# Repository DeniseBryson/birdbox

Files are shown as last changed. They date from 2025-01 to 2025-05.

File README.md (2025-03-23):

# BirdsOS

BirdsOS is a Flask-based application for controlling and monitoring bird feeder hardware, with support for camera feeds and GPIO control. It includes development-friendly mock implementations for testing without physical hardware.

## Features

### Camera System
- Live video streaming with configurable resolution
- Recording capabilities with frame buffering
- Camera settings management
- Mock implementation for development with test pattern generation

### GPIO Control
- Hardware abstraction layer with Raspberry Pi detection
- Pin state monitoring and control
- Mock implementation for development and testing
- Interactive GPIO simulator interface

### Web Interface
- Main dashboard for system monitoring
- Camera simulator with live feed display
- GPIO simulator for hardware interaction
- RESTful API endpoints for system control

## Setup

1. Clone the repository:
```bash
git clone <repository-url>
cd birdbox
```

2. Install dependencies:
```bash
pip install -r requirements.txt
```

3. Run the application:
```bash
python app.py
```

The application will be available at:
- Main Dashboard: http://localhost:5000
- Camera Simulator: http://localhost:5000/camera
- GPIO Simulator: http://localhost:5000/gpio

## API Endpoints

### Camera Control
- `GET /video_feed` - Stream live video feed
- `POST /api/camera/record/start` - Start recording
- `POST /api/camera/record/stop` - Stop recording
- `POST /api/camera/settings` - Update camera settings
- `GET /api/camera/recordings` - List recorded videos

### GPIO Control
- `GET /api/gpio/status` - Get current pin states
- `POST /api/gpio/trigger` - Trigger input pin state change

### System Status
- `GET /status` - Get system operational status

## Development

The system includes mock implementations for both camera and GPIO functionality, allowing development and testing without physical hardware. When running on a Raspberry Pi, it automatically switches to using real hardware interfaces.

### Mock Implementations
- Camera mock generates test patterns with timestamps
- GPIO mock simulates pin state management
- Both provide realistic behavior for testing

## Current Status

### Implemented
- Core application structure
- Camera streaming and recording framework
- GPIO state management
- Web interface and simulators
- Hardware abstraction layer

### In Progress
- Motor control system
- Recording storage implementation
- Full status monitoring
- Enhanced simulator features

## Contributing

Contributions are welcome! Please feel free to submit pull requests or open issues for bugs and feature requests.

## License

[License information to be added]

# BirdBox - Training Wild Birds to Clean the Environment

The BirdBox project is an innovative approach to environmental cleanup that trains wild birds to collect litter in exchange for food. This project combines environmental conservation with animal intelligence, creating a sustainable way to help clean our environment while engaging with local wildlife.

## Overview

The BirdBox is a device designed to train wild crows to pick up litter and deposit it into a designated container in exchange for food rewards. This project leverages the natural intelligence and adaptability of corvids (crows and ravens) to create a mutually beneficial relationship between humans and birds while addressing environmental pollution.

## How It Works

The system works on a simple principle: when a bird deposits litter into the collection area, it triggers sensors that activate a food dispenser, rewarding the bird with a treat. Over time, birds learn to associate cleaning up litter with receiving food rewards, creating a sustainable cycle of environmental cleanup.

## Project Goals

- Create a sustainable solution for environmental cleanup
- Engage wild birds in a meaningful way that benefits both wildlife and humans
- Raise awareness about environmental issues and animal intelligence
- Demonstrate how technology can be used to create innovative solutions for environmental challenges

## Community Impact

This project not only helps clean the environment but also:
- Creates awareness about environmental pollution
- Demonstrates the intelligence of wild birds
- Provides a unique way for communities to engage with local wildlife
- Offers an educational opportunity to learn about animal behavior and environmental conservation

## Contributing

This is an open-source project, and we welcome contributions from the community. Whether you're interested in hardware improvements, software development, or documentation, your input is valuable to the project's success.

## License

This project is licensed under the Creative Commons - Attribution - Non-Commercial license.

Spezifikation:
Motordurchmesser: 6 mm
Motorlänge: 12 mm
Kabellänge: 65 mm
Gewicht: 2 g
Spannungsbereich: 3,0 V -3,7 V
Testdaten:
Spannung: 3,0 V Strom: 160 mA
Spannung: 3,7 V Strom: 220 mA

# Camera Case
The Camera Case was used from https://www.thingiverse.com/thing:2317664 and modified, to make it attachable to the backboard.

## Installation

### Automated Setup (Raspberry Pi)

The project includes an automated setup script designed for Raspberry Pi (optimized for Pi 3B). The script handles all necessary installation steps, including:
- System dependencies
- Python environment
- Hardware configuration
- Service setup
- Storage management

#### Prerequisites
- Raspberry Pi (3B recommended) with Raspberry Pi OS
- Internet connection
- GitHub account (for SSH key setup)
- At least 32GB SD card (Class 10 recommended)

#### Installation Steps

1. **Download the Setup Script**
   ```bash
   curl -O https://raw.githubusercontent.com/DeniseBryson/birdbox/AIgen2/setup.sh
   chmod +x setup.sh
   ```
   or upload via scp:
   ```bash
   scp "setup.sh" birds@<ip-address>:/home/birds/
   ```

2. **Run the Setup Script**
   ```bash
   ./setup.sh
   ```

   The script will:
   - Check if running on a Raspberry Pi
   - Set up SSH keys if needed
   - Install all dependencies
   - Configure camera and GPIO interfaces
   - Set up the Python environment
   - Create necessary directories
   - Configure storage based on available space
   - Run tests to verify the installation
   - Set up the system service

3. **Post-Installation**
   - The service will start automatically
   - Access the web interface at `http://localhost:5000`
   - Check the service status with `sudo systemctl status birdbox`

#### Configuration
The script creates a `.env` file with default settings optimized for Raspberry Pi 3B:
- Camera: 640x480 @ 20fps
- Storage: 75% of available SD card space
- GPIO: BCM mode
- Logging: Daily rotation, 14 days retention

#### Troubleshooting
- If tests fail during installation, you can choose to:
  1. Exit and fix the issues
  2. Continue with the installation (not recommended)
- Check logs in `~/birdbox/storage/logs/`
- Monitor system temperature with `vcgencmd measure_temp`
- Monitor resources with `htop`

#### Manual Installation
For non-Raspberry Pi systems or manual installation, please refer to the [Manual Installation Guide](docs/manual_installation.md).

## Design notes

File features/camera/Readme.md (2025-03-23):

# Camera Feature Documentation

## Overview
The camera feature provides functionality for camera control, live streaming, and video recording in BirdsOS.

## API Endpoints

### Status and Control
- `GET /api/v1/camera/status`
  - Returns camera status and available devices
  - Response: 
    ```json
    {
      "active_camera": 0,
      "status": "active",
      "camera_info": {
        "id": 0,
        "resolution": [1280, 720],
        "is_running": true,
        "status": "active"
      },
      "available_cameras": [
        {"id": 0, "status": "available"}
      ]
    }
    ```

- `POST /api/v1/camera/initialize/<camera_id>`
  - Initialize and start a specific camera
  - Response (success):
    ```json
    {
      "status": "success",
      "message": "Camera {id} initialized"
    }
    ```
  - Response (error):
    ```json
    {
      "status": "error",
      "message": "Failed to initialize camera {id}"
    }
    ```

- `POST /api/v1/camera/stop`
  - Stop the currently active camera
  - Response:
    ```json
    {
      "status": "success",
      "message": "Camera stopped"
    }
    ```

## Technical Details

### Camera Class
The `Camera` class provides low-level camera operations:
- Device initialization
- Frame capture
- Status monitoring
- Device enumeration

### Camera Manager
The `CameraManager` handles:
- Camera lifecycle management
- High-level operations
- Status tracking
- Resource cleanup

## Dependencies
- OpenCV (`opencv-python==4.9.0.80`)
- NumPy (`numpy<2.0`)
- Flask for API endpoints

## Testing
All components are tested with:
- Unit tests for Camera class
- Unit tests for CameraManager
- Integration tests for routes
- Mocked hardware for reliable testing

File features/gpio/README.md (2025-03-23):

# GPIO Control Feature

This feature provides comprehensive GPIO (General Purpose Input/Output) control functionality for the BirdsOS project, with support for both real Raspberry Pi hardware and development environments.

## Features

- Hardware abstraction layer for GPIO control
- Real-time pin state monitoring
- Input/Output mode configuration
- Pin state toggling for output pins
- Mock implementation for development
- WebSocket-based real-time updates
- Comprehensive test coverage

## Quick Start

1. Import and register the GPIO blueprints in your Flask app:

```python
from features.gpio import gpio_bp, sock

app.register_blueprint(gpio_bp)
sock.init_app(app)
```

2. Access the GPIO control interface at `/gpio`

## API Endpoints

### Get Available Pins
```http
GET /api/gpio/pins

Response:
{
    "status": "success",
    "pins": [2, 3, 4, ...],
    "states": {
        "2": {
            "pin": 2,
            "mode": "IN",
            "state": 0,
            "name": "GPIO2"
        },
        ...
    }
}
```

### Configure Pin Mode
```http
POST /api/gpio/configure
Content-Type: application/json

{
    "pin": 2,
    "mode": "OUT"  // "IN" or "OUT"
}

Response:
{
    "status": "success",
    "state": {
        "pin": 2,
        "mode": "OUT",
        "state": 0,
        "name": "GPIO2"
    }
}
```

### Set Pin State
```http
POST /api/gpio/state
Content-Type: application/json

{
    "pin": 2,
    "state": 1  // 0 or 1
}

Response:
{
    "status": "success",
    "state": {
        "pin": 2,
        "mode": "OUT",
        "state": 1,
        "name": "GPIO2"
    }
}
```

### Cleanup GPIO Resources
```http
POST /api/gpio/cleanup

Response:
{
    "status": "success",
    "message": "GPIO cleanup completed"
}
```

## WebSocket Updates

Connect to `/ws/gpio-updates` for real-time GPIO state updates:

```javascript
const ws = new WebSocket('ws://' + location.host + '/ws/gpio-updates');
ws.onmessage = (event) => {
    const data = JSON.parse(event.data);
    if (data.type === 'gpio_update') {
        // Handle pin states update
        console.log(data.data.states);
    }
};
```

## Development

### Running Tests

```bash
pytest features/gpio/tests/
```

### Mock Implementation

The feature automatically detects if it's running on a Raspberry Pi. If not, it uses a mock implementation that simulates GPIO behavior, perfect for development and testing.

### Adding New GPIO Features

1. Implement the feature in `manager.py`
2. Add corresponding API endpoints in `routes.py`
3. Add tests in `tests/`
4. Update the UI in `templates/gpio_control.html`

## Example Usage

### Python Code
```python
from features.gpio import GPIOManager

# Initialize GPIO manager
gpio = GPIOManager()

# Configure pin as output
gpio.configure_pin(18, 'OUT')

# Set pin high
gpio.set_pin_state(18, 1)

# Get pin state
state = gpio.get_pin_state(18)
print(f"Pin 18 is {'HIGH' if state['state'] else 'LOW'}")

# Cleanup when done
gpio.cleanup()
```

### JavaScript Code
```javascript
// Initialize GPIO controller
const controller = new GPIOController();

// Configure pin as output
await controller.configurePin(18, 'OUT');

// Toggle pin state
await controller.togglePinState(18, 1);
```

## Security Considerations

1. Pin access is restricted to valid GPIO pins only
2. Input validation for all API endpoints
3. Error handling for hardware failures
4. Automatic cleanup on application shutdown

## Contributing

1. Fork the repository
2. Create a feature branch
3. Add your changes
4. Add tests for your changes
5. Submit a pull request

## License

This feature is part of the BirdsOS project and is licensed under the same terms.

## Test Coverage TODO

### UI Tests
- [ ] Test pin selection dropdown population
- [ ] Test mode switching (Input/Output)
- [ ] Test pin state indicators
- [ ] Test pin overview table updates
- [ ] Test toggle button functionality
- [ ] Test real-time updates
- [ ] Test mobile responsiveness
- [ ] Test browser compatibility (Chrome, Firefox, Safari)
- [ ] Test concurrent user interactions
- [ ] Test UI state consistency with backend
- [ ] Test UI behavior during network latency

### Error Handling Tests
- [ ] Test concurrent access to same GPIO pin
- [ ] Test hardware access failures
- [ ] Test application shutdown cleanup
- [ ] Test WebSocket connection drops
- [ ] Test invalid API responses
- [ ] Test error message display in UI
- [ ] Test recovery after errors
- [ ] Test rate limiting behavior
- [ ] Test timeout handling
- [ ] Test invalid state transitions

### Performance Tests
- [ ] Test response time under load
- [ ] Test WebSocket update frequency
- [ ] Test memory usage with multiple clients
- [ ] Test WebSocket client cleanup
- [ ] Test UI performance with many pins
- [ ] Test rapid state changes
- [ ] Test concurrent API requests
- [ ] Test data throughput limits
- [ ] Test browser resource usage
- [ ] Test backend resource usage

### Integration Tests
- [ ] Test GPIO and motor control interaction
- [ ] Test state persistence across restarts
- [ ] Test mock/real hardware switching
- [ ] Test rapid mode switching
- [ ] Test with other system components
- [ ] Test startup sequence
- [ ] Test shutdown sequence
- [ ] Test system state recovery
- [ ] Test configuration changes
- [ ] Test logging integration

### Security Tests
- [ ] Test access control for endpoints
- [ ] Test input sanitization
- [ ] Test WebSocket authentication
- [ ] Test API rate limiting
- [ ] Test permission levels
- [ ] Test data validation
- [ ] Test error exposure
- [ ] Test secure connections
- [ ] Test session handling
- [ ] Test audit logging

### Edge Cases
- [ ] Test boundary values for pin numbers
- [ ] Test maximum WebSocket connections
- [ ] Test invalid JSON payloads
- [ ] Test unicode input
- [ ] Test large data payloads
- [ ] Test rapid connection/disconnection
- [ ] Test browser tab switching
- [ ] Test system resource limits
- [ ] Test error condition combinations
- [ ] Test recovery scenarios

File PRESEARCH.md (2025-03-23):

# BirdBox Web Interface - Pre-Research Document

## 1. Core Features Overview

### 1.1 Storage & Statistics
- Local storage on Raspberry Pi
- Default 10GB storage limit
- Warning at 85% capacity
- Hourly statistics
- CSV export capability

```python
class StorageManager:
    DEFAULT_STORAGE_LIMIT = 10 * 1024 * 1024 * 1024  # 10GB
    WARNING_THRESHOLD = 0.85

    def check_storage(self):
        total, used, free = shutil.disk_usage("/")
        return {
            "total": total,
            "used": used,
            "free": free,
            "warning": used / total > self.WARNING_THRESHOLD
        }
```

### 1.2 Configuration Profiles
- Persistent storage
- Multiple profiles support
- Configurable parameters:
  - Motor frequencies
  - Sensor sensitivity
  - Feeding delays

```python
class ConfigProfile:
    def __init__(self):
        self.config = {
            "name": "Default",
            "motor_frequency": {
                "min": 10,
                "max": 100,
                "default": 50
            },
            "sensor_sensitivity": 0.75,
            "feeding_delay": 5  # seconds
        }
```

### 1.3 Maintenance Functions
- Food level estimation based on motor runtime
- Statistical optimization
- Manual reset with backdating capability
- Basic maintenance logging

```python
class FoodLevelEstimator:
    def __init__(self):
        self.motor_runtime = 0
        self.last_refill = datetime.now()
        self.food_per_second = 0.5  # g/s
```

### 1.4 Notifications (Telegram)
- Internet connectivity check
- Configuration via UI
- Visual status indication
- Priority levels

```python
class NotificationManager:
    def __init__(self):
        self.telegram_token = None
        self.chat_id = None

    def check_connection(self):
        try:
            return requests.get('https://api.telegram.org',
                              timeout=5).status_code == 200
        except:
            return False
```

### 1.5 Camera Integration
- Buffer: 10s before trigger
- Post-event: 20s after motor stop
- Configurable resolution
- Storage management
- Email warnings before deletion

```python
class CameraManager:
    def __init__(self):
        self.buffer_time = 10
        self.post_time = 20
        self.resolution = (1280, 720)
        self.format = 'h264'
```

### 1.6 Research Data
- CSV export functionality
- Configurable data points
- Offline availability
- Storage monitoring

```python
class ResearchData:
    data_points = {
        "timestamp": [],
        "sensor_triggers": [],
        "motor_runtime": [],
        "estimated_food": [],
        "temperature": [],
        "video_references": []
    }
```

## 2. UI Design

### 2.1 Dashboard Layout
```html
<div class="dashboard">
    <div class="stats-cards">
        <!-- Statistics Cards -->
    </div>
    <div class="charts">
        <!-- Interactive Charts -->
    </div>
    <div class="config-panel">
        <!-- Configuration Interface -->
    </div>
</div>
```

### 2.2 Responsive Design
- Mobile-first approach
- Flexible grid system
- Touch-friendly controls

## 3. Future Extensions

### 3.1 Bird Species Recognition
- TensorFlow Lite implementation
- Pre-trained MobileNet model
- Transfer learning capability
- Local inference
- Movement pre-filtering

### 3.2 Advanced Analytics
- Pattern recognition
- Behavior analysis
- Weather correlation
- Feeding optimization

## 4. Technical Requirements

### 4.1 Hardware
- Raspberry Pi
- Camera module
- GPIO sensors
- Motors
- SD card (min. 16GB recommended)

### 4.2 Software
- Python 3.7+
- Flask
- OpenCV
- TensorFlow Lite (optional)
- SQLite/JSON storage

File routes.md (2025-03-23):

# BirdsOS Route Structure

## Main Routes

### Dashboard (/)
- Main system overview
- Quick status cards
- Latest activity feed
- System health indicators

### Camera (/camera)
- Live video feed
- Recording controls
- Camera settings
- Recent recordings list

### Hardware Control (/hardware)
- GPIO status and control
- Motor controls
- Sensor readings
- Hardware diagnostics

### Configuration (/config)
- System settings
- Profile management
- Hardware configuration
- Notification settings

### Maintenance (/maintenance)
- Food level monitoring
- System maintenance
- Storage management
- Backup controls

### Analytics (/analytics)
- Activity statistics
- Bird visit data
- Feeding patterns
- Weather correlation

## API Routes

### System API (/api/v1/system)
- GET  /status
- POST /restart
- GET  /storage
- GET  /health

### Camera API (/api/v1/camera)
- GET  /stream
- POST /record/start
- POST /record/stop
- GET  /recordings
- POST /settings

### Hardware API (/api/v1/hardware)
- GET  /gpio/status
- POST /gpio/trigger
- GET  /motors/status
- POST /motors/control
- GET  /sensors/readings

### Configuration API (/api/v1/config)
- GET  /profiles
- POST /profiles
- PUT  /profiles/{id}
- GET  /settings
- PUT  /settings

### Maintenance API (/api/v1/maintenance)
- GET  /food-level
- POST /food-refill
- GET  /storage/status
- POST /backup

### Analytics API (/api/v1/analytics)
- GET  /statistics
- GET  /visits
- GET  /patterns
- GET  /weather-data

## WebSocket Routes (/ws)
- /camera-feed
- /sensor-updates
- /system-status
- /notifications

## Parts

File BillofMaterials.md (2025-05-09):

|Description | Name | Amount  | EAN  | Price  | Comment |
|---|---|---|---|---|---|
| Water proof case for electronics 34cmx23cmx12,5cm | Wetterschutzbox  |  1 | 4007123673896  | 25 € (Germany, 2024)  ||
| M3 Screw  | ISO 1207 - M3 x 10 <br>ISO 1207 - M3 x 16<br>ISO 1207 - M3 x 30|8<br>8<br>8  | | 3 x 2,19 € (Germany, 2024)  ||
| hose for the nuts to fall 19mm inside/appr. 22mm outside | Ablaufschlauch | 1m  | 4007111115797  | 7,20 € (Germany, 2024)  |Could be bigger|
|M3 Nuts| ISO 4032 - M3|30|-|69,50 €/kg (Germany, 2024) | |
|rubber seal|Ventilteller-Dichtung|4|4053452014435||to cushion the feeder|
|IR EMITTER 940NM 100MA RADIAL| TSAL 6400 |4|-|0,25 € (Germany, 2024)|opitcal gate emitter|
|SENSOR PHOTODIODE 900NM| SFH 203 FA |2|-|0,90 € (Germany, 2024)|opitcal gate reciever|
|Comperator|LM324L|1|-|1 € (Germany, 2025)|Creates a clear on and off signal of the optical gate reciever outputs|
|Resistors|1M Ohm <br> 220 Ohm <br> 22k Ohm |4 <br> 2 <br> 1|-|0,10 €|Can just be bought in sets|
|Potentiometer|10kOhm Potentiometer|1|-|1€|To set the comparative voltage for the Comperator|
|MOSFET Motor Control Module|D4184 Mosfet Module|1|-|2,90 € (Germany, 2025)||
|DC Motor |DC 3V,3800rpm, D=17x23mm|1b\s-|2,50€ (Germany, 2025)||
|Wires||||||
|LAN Cable|-|1|-|-|An old cable with 8 wires to connect the optical food gate with the box, choose most flexible|
|Raspberry Pi|Raspberry Pi 3 Model B|1|-|appr. 30 €|Any Pi will work as long it has enough pins|

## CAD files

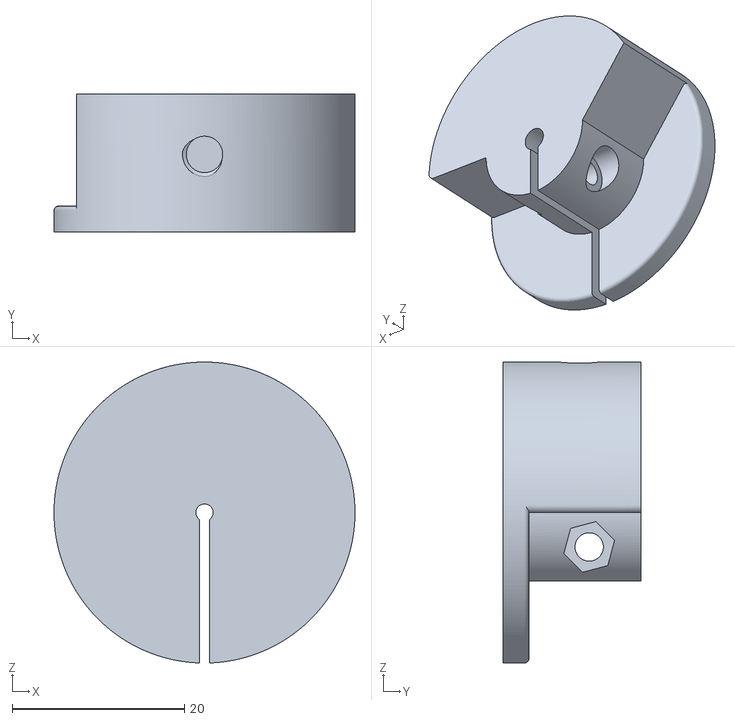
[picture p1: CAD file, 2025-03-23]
DesignFiles/birdbox/ModifiedFiles/BirdBox_vibr_flywheel_3mm.stl
35.0 x 16.0 x 35.0

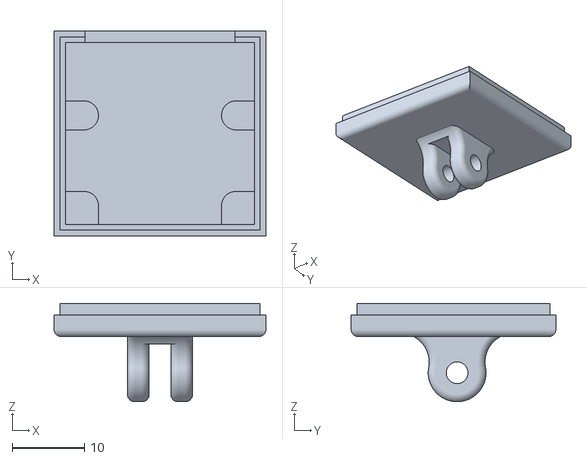
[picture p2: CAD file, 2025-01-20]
DesignFiles/CameraMount/Bottom_CameraCase.stl
29.3 x 28.3 x 13.6

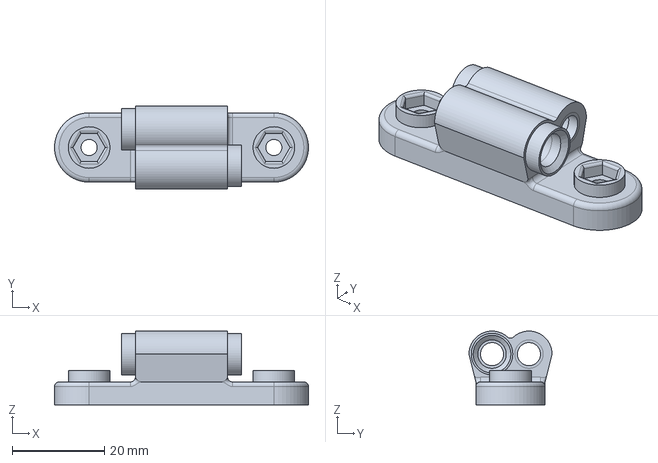
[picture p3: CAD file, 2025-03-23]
DesignFiles/VibroTroughFeeder/ModifiedFiles/VibroMotorMount_processdirection.FCStd
55.0 x 18.0 x 16.0 mm

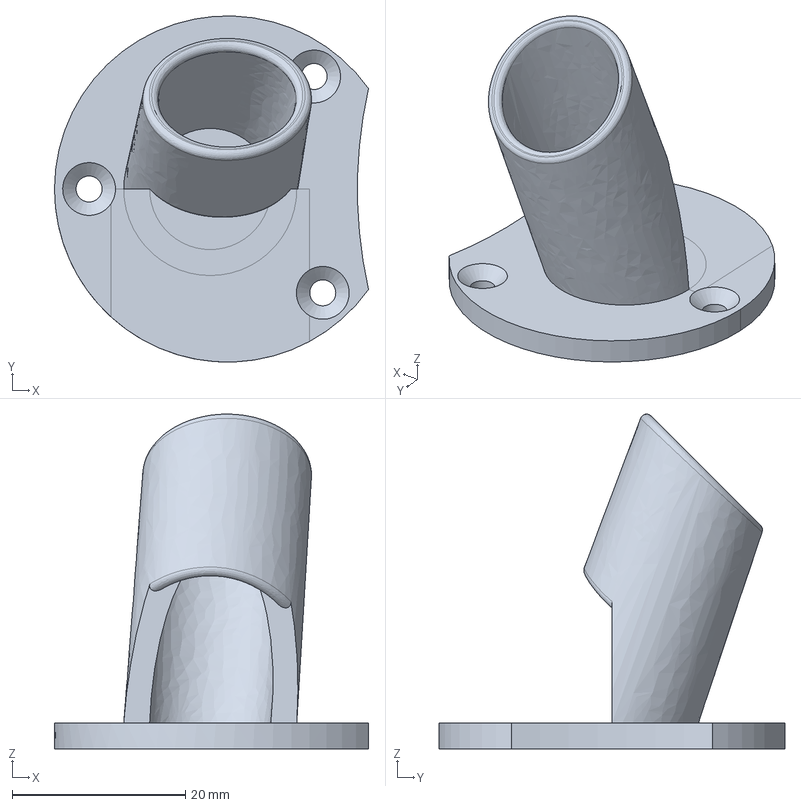
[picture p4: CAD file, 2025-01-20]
DesignFiles/birdbox/ModifiedFiles/NutReciever_Male.FCStd
36.3 x 40.0 x 38.7 mm

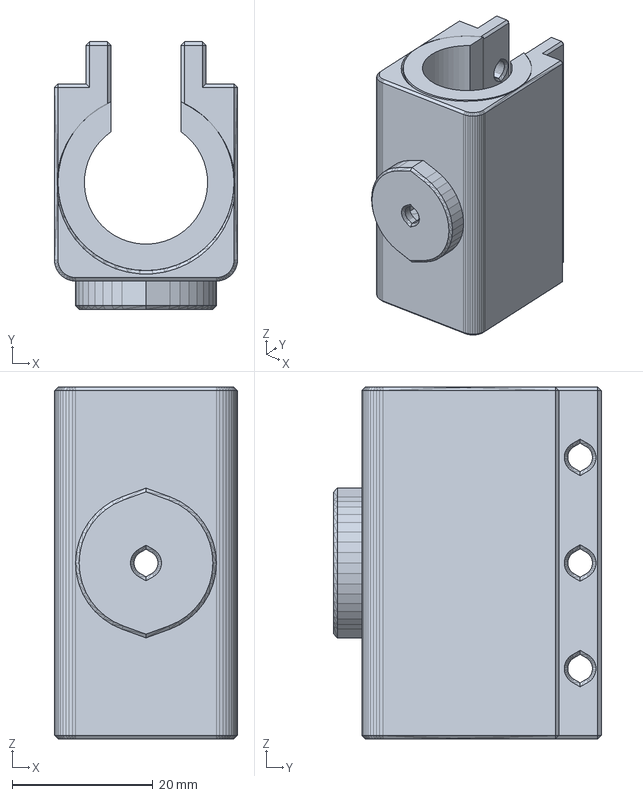
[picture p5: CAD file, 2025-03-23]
DesignFiles/VibroTroughFeeder/ModifiedFiles/Vibrating_Motor_Mount-Linear_Vibrator_Measured.FCStd
26.0 x 38.0 x 50.0 mm

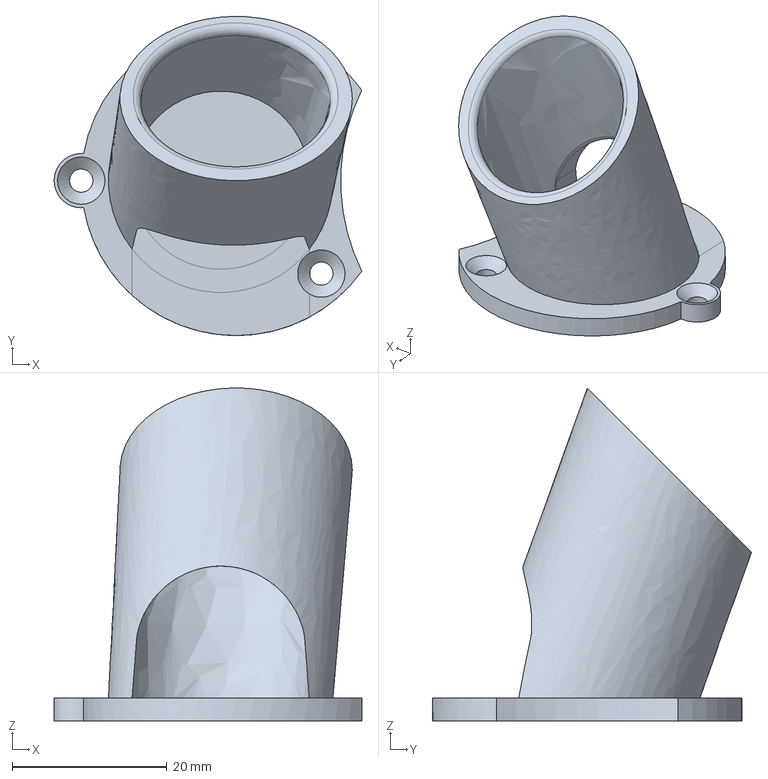
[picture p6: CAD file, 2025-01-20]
DesignFiles/birdbox/ModifiedFiles/NutReciever.FCStd
39.7 x 41.2 x 43.0 mm

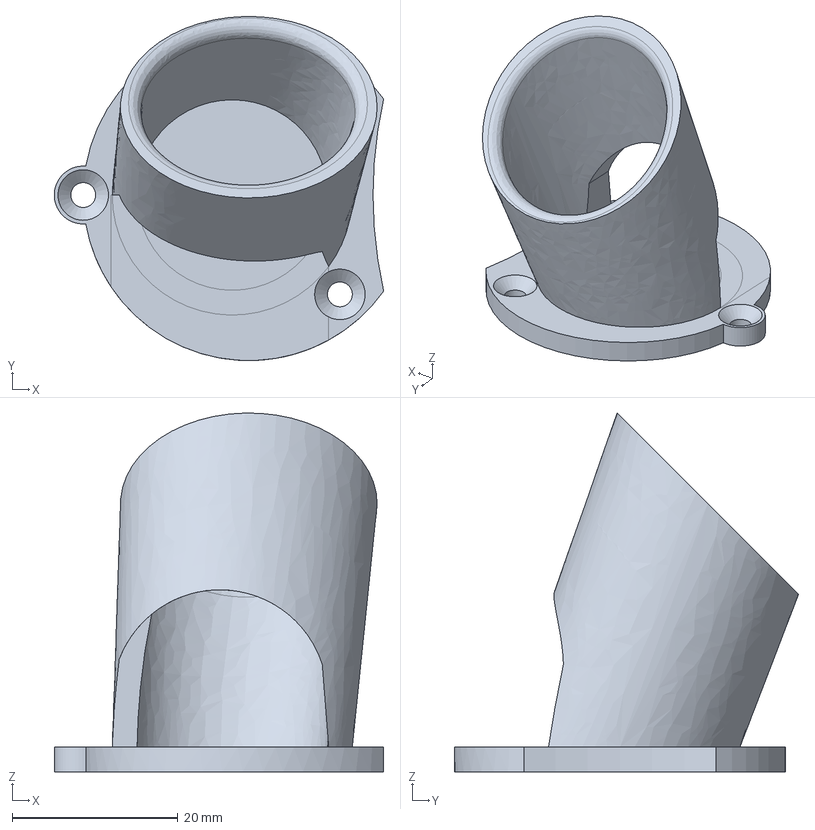
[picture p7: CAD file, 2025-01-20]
DesignFiles/birdbox/ModifiedFiles/NutReciever_Female.FCStd
39.8 x 41.5 x 43.3 mm

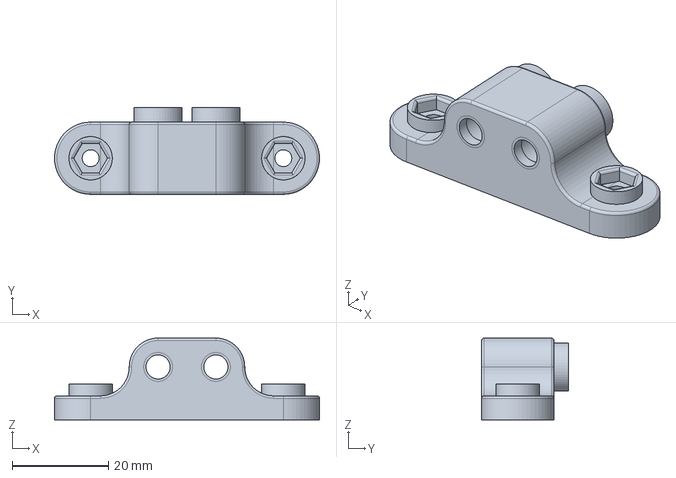
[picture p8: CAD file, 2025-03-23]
DesignFiles/VibroTroughFeeder/ModifiedFiles/VibroMotorMount.FCStd
55.0 x 18.0 x 17.0 mm

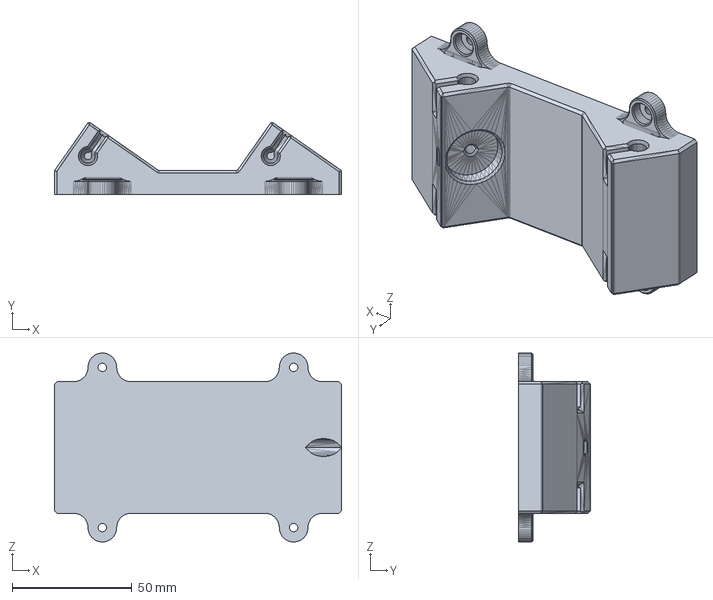
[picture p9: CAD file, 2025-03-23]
DesignFiles/VibroTroughFeeder/ModifiedFiles/BottomVibroMountPlate.FCStd
120.0 x 30.1 x 79.0 mm

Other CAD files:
DesignFiles/CameraMount/Bottom_MountHorizontal.FCStd
DesignFiles/VibroTroughFeeder/ModifiedFiles/VibroMotorMount_17mm.stl
DesignFiles/VibroTroughFeeder/ModifiedFiles/VibroMotorMount_processdirection.stl
DesignFiles/birdbox/ModifiedFiles/NutReciever_Female.stl
DesignFiles/birdbox/ModifiedFiles/NutReciever_Male.stl

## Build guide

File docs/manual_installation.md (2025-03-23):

# Manual Installation Guide

This guide provides step-by-step instructions for manually installing BirdsOS on any system. While the project is optimized for Raspberry Pi, you can run it on other systems for development or testing purposes.

## System Requirements

### Minimum Requirements
- Python 3.7 or higher
- 1GB RAM
- 1GB free disk space
- Webcam (for camera features)
- GPIO capability (for hardware control features)

### Development Mode Requirements
- Python 3.7 or higher
- 2GB RAM
- 5GB free disk space
- Any webcam (optional, mock camera available)
- No GPIO required (mock GPIO available)

## Installation Steps

### 1. Prepare the Environment

```bash
# Create and enter project directory
mkdir birdbox
cd birdbox

# Create Python virtual environment
python3 -m venv venv
source venv/bin/activate  # On Windows: .\venv\Scripts\activate
```

### 2. Clone the Repository

```bash
git clone https://github.com/DeniseBryson/birdbox.git .
```

### 3. Install Dependencies

```bash
# Upgrade pip
pip install --upgrade pip

# Install system packages (Ubuntu/Debian)
sudo apt-get update
sudo apt-get install -y \
    python3-opencv \
    libatlas-base-dev \
    libgstreamer1.0-0 \
    gstreamer1.0-tools \
    gstreamer1.0-plugins-good

# Install Python requirements
pip install -r requirements.txt
```

For other operating systems, install equivalent packages using your system's package manager.

### 4. Create Configuration

Create a `.env` file in the project root:

```bash
# Create and edit .env file
cat > .env << EOL
# BirdsOS Environment Configuration
FLASK_APP=app.py
FLASK_ENV=development  # Change to 'production' for production setup
SECRET_KEY=$(python3 -c 'import secrets; print(secrets.token_hex(16))')
MAX_CONTENT_LENGTH=16777216

# Storage Configuration
STORAGE_PATH=./storage
MAX_STORAGE_GB=5
WARNING_THRESHOLD=0.85

# Camera Configuration
CAMERA_RESOLUTION_WIDTH=640
CAMERA_RESOLUTION_HEIGHT=480
CAMERA_FRAMERATE=30
CAMERA_FORMAT=h264
CAMERA_BUFFER_TIME=5
CAMERA_POST_TIME=10

# GPIO Configuration
ENABLE_HARDWARE=false  # Set to true only if GPIO hardware is available
GPIO_MODE=BCM

# WebSocket Configuration
WS_ENABLED=true

# Testing Configuration
TESTING=false
EOL
```

### 5. Create Required Directories

```bash
# Create storage structure
mkdir -p storage/{recordings,logs}
```

### 6. Run Tests

```bash
# Run the test suite
python -m pytest
```

### 7. Development Server

```bash
# Start the development server
python app.py
```

The application will be available at `http://localhost:5000`

## Production Deployment

For production deployment, additional steps are recommended:

### Using Systemd (Linux)

1. Create a service file:
```bash
sudo nano /etc/systemd/system/birdbox.service
```

2. Add the following content (adjust paths as needed):
```ini
[Unit]
Description=BirdsOS Web Interface
After=network.target

[Service]
User=<your-username>
WorkingDirectory=/path/to/birdbox
Environment="PATH=/path/to/birdbox/venv/bin"
Environment="PYTHONUNBUFFERED=1"
Environment="FLASK_APP=app.py"
Environment="FLASK_ENV=production"
ExecStart=/path/to/birdbox/venv/bin/python app.py
Restart=always
RestartSec=10

[Install]
WantedBy=multi-user.target
```

3. Enable and start the service:
```bash
sudo systemctl enable birdbox
sudo systemctl start birdbox
```

### Using Docker

A Dockerfile is provided for containerized deployment. Build and run with:

```bash
docker build -t birdbox .
docker run -p 5000:5000 birdbox
```

## Troubleshooting

### Common Issues

1. **Camera Not Working**
   - Check if OpenCV is installed correctly
   - Verify camera permissions
   - Try running with mock camera: Set `ENABLE_HARDWARE=false` in `.env`

2. **GPIO Errors**
   - Verify GPIO library installation
   - Check hardware permissions
   - Use mock GPIO for testing: Set `ENABLE_HARDWARE=false` in `.env`

3. **Permission Issues**
   - Ensure correct file permissions on storage directories
   - Check user permissions for camera/GPIO access

### Logs

- Application logs: `storage/logs/birdbox.log`
- Error logs: `storage/logs/birdbox_error.log`

## Development Mode

For development, set these environment variables:
```bash
export FLASK_ENV=development
export FLASK_DEBUG=1
```

This enables:
- Debug mode
- Auto-reload on code changes
- Detailed error pages
- Mock hardware support

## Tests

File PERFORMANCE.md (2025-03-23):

# BirdsOS Deployment Guide - Raspberry Pi 3B

## Hardware Limitations & Considerations

### Memory (1GB RAM)
- Monitor memory usage with multiple WebSocket connections
- Implement cleanup routines for unused resources
- Limit video buffer sizes
- Consider reducing default camera resolution

### Storage
- Default 10GB storage limit should be adjusted:

```python
DEFAULT_STORAGE_LIMIT = 5 1024 1024 1024 # 5GB instead of 10GB
WARNING_THRESHOLD = 0.80 # Earlier warning
```

- Use high-quality Class 10 SD card (minimum 16GB recommended)

### GPIO
- 40 GPIO pins available
- 3.3V voltage levels only
- Use hardware PWM pins for motor control
- Consider cooling solutions for multiple GPIO outputs

## Performance Optimizations

### Camera Settings

```python
    class CameraManager:
    def init(self):
    self.buffer_time = 5 # Reduced from 10s
    self.post_time = 10 # Reduced from 20s
    self.resolution = (640, 480) # Lower resolution
    self.format = 'h264' # Hardware encoding
```

### Background Tasks

```python
from threading import Timer
class OptimizedStorageManager:
def schedule_cleanup(self):
Timer(3600, self.cleanup_old_files).start() # Hourly cleanup
```

### Database Optimization

```python
import sqlite3
class ResearchData:
def init(self):
self.db_path = 'research.db'
self.init_db()
def init_db(self):
with sqlite3.connect(self.db_path) as conn:
conn.execute('''CREATE TABLE IF NOT EXISTS measurements
(timestamp INTEGER PRIMARY KEY,
sensor_triggers INTEGER,
motor_runtime REAL)''')
```

## Software Setup

### Operating System
- Use Raspberry Pi OS Lite (minimal) for better performance

### Required Packages

```bash
sudo apt-get update
sudo apt-get install -y python3-pip python3-opencv
sudo apt-get install -y libatlas-base-dev # For numpy
sudo apt-get install -y python3-rpi.gpio
```

### Python Dependencies
Create `requirements.txt`:
```text
Flask
RPi.GPIO
opencv-python-headless # Lighter than full opencv
numpy
requests # For Telegram notifications
```

### Network Configuration
```bash
sudo raspi-config
Enable:
- Camera
- SSH (for remote management)
- I2C (if using sensors)
```

## System Service Setup

Create service file at `/etc/systemd/system/birdsos.service`:
```ini
[Unit]
Description=BirdsOS Service
After=network.target
[Service]
ExecStart=/usr/bin/python3 /path/to/app.py
WorkingDirectory=/path/to/project
User=pi
Restart=always
Environment=PYTHONUNBUFFERED=1
[Install]
WantedBy=multi-user.target
```
Enable and start service:

```bash
sudo systemctl enable birdsos
sudo systemctl start birdsos
```

## Monitoring

### System Resource Monitoring
```python
import psutil
def check_system_resources():
return {
"cpu_percent": psutil.cpu_percent(),
"memory_percent": psutil.virtual_memory().percent,
"disk_percent": psutil.disk_usage('/').percent,
"temperature": get_cpu_temperature()
}
def get_cpu_temperature():
try:
with open('/sys/class/thermal/thermal_zone0/temp', 'r') as f:
return float(f.read().strip()) / 1000
except:
return None
```

## Pre-deployment Checklist

1. Hardware
   - [ ] SD card installed and formatted
   - [ ] Camera module connected
   - [ ] GPIO connections verified
   - [ ] Cooling solution in place if needed

2. Software
   - [ ] OS installed and updated
   - [ ] Required packages installed
   - [ ] Python dependencies installed
   - [ ] Service file configured

3. Configuration
   - [ ] Storage limits adjusted
   - [ ] Camera settings optimized
   - [ ] Network interfaces enabled
   - [ ] Database initialized

4. Testing
   - [ ] Memory usage monitored
   - [ ] Camera functionality verified
   - [ ] GPIO operations tested
   - [ ] Service auto-restart confirmed

## Maintenance Recommendations

1. Regular Monitoring
   - Check system logs daily
   - Monitor storage usage
   - Review temperature readings
   - Verify database size

2. Periodic Tasks
   - Clean old log files
   - Backup database
   - Update system packages
   - Check SD card health

3. Performance Checks
   - Monitor memory leaks
   - Check CPU usage patterns
   - Verify camera buffer handling
   - Test GPIO responsiveness

## Troubleshooting

### Common Issues
1. High Memory Usage
   - Check WebSocket connections
   - Verify video buffer cleanup
   - Monitor Python process memory

2. Storage Problems
   - Review cleanup routines
   - Check log rotation
   - Verify database size

3. GPIO Issues
   - Verify voltage levels
   - Check pin assignments
   - Test for interference

### Debug Commands

```bash
Check service status
sudo systemctl status birdsos
View logs
journalctl -u birdsos
Monitor system resources
top
htop (if installed)
Check temperature
vcgencmd measure_temp
View GPIO status
gpio readall
```

## Notes
- Always test thoroughly with actual hardware
- Monitor performance during initial deployment
- Keep backup of SD card after successful setup
- Document any custom modifications

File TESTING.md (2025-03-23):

# Testing BirdsOS

## Manual Testing with curl

1. Start the server:
```bash
python app.py
```

2. Run the curl test script:
```bash
./test_routes.sh
```

This will test all endpoints and display their responses.

## Automated Testing

1. Install test dependencies:
```bash
pip install -r requirements.txt
```

2. Run the tests:
```bash
pytest tests/test_routes.py -v
```

## Test Coverage

The tests verify:
- All main UI routes return 200 status
- All API endpoints return valid JSON responses
- Basic response structure for each endpoint
- WebSocket endpoints existence (connection testing in separate suite)

## Adding New Tests

1. For new UI routes:
   - Add route test in `tests/test_routes.py`
   - Verify template existence
   - Check response status

2. For new API endpoints:
   - Add endpoint test in `tests/test_routes.py`
   - Verify JSON response structure
   - Test all HTTP methods

3. For WebSocket endpoints:
   - Add connection test
   - Test message handling
   - Test disconnection handling

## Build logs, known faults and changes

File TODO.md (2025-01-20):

17.01.2025
- [ ] Akkus testen
- [ ] Motorsteuerung (+ DC Motor) kaufen

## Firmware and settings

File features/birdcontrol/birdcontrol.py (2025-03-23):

import logging
from features.birdcontrol.motor_controller import MotorController
from features.birdcontrol.optical_gates import OpticalGates
from config.settings import MOTOR_CONFIG, PIN_CONFIG
import time

logger = logging.getLogger(__name__)

class BirdControl:
    """
    Manages the control of two motors by reading the state of the optical gates.
    """
    def __init__(self):
        self.motors = MotorController()
        self.start_pin = PIN_CONFIG['OPTICAL_GATE_1_PIN']
        self.end_pin = PIN_CONFIG['OPTICAL_GATE_2_PIN']
        self.is_running = False
        self.timeout = MOTOR_CONFIG['MAX_ON_TIME']

        def callback(pin: int, state: int) -> None:
            logger.debug(f"Callback triggerd. Pin {pin} state changed to {state}")
            if pin == self.start_pin:
                if not self.is_running:
                    logger.debug(f"RÜTTELN!!")
                    self.motors.turn_on()
                    time.sleep(self.timeout)
                    logger.debug(f"RUHE IN DER KISTE!!")
                    self.motors.turn_off()
                    self.is_running = False
            elif pin == self.end_pin:
                self.motors.turn_off()
                self.is_running = False
                logger.debug(f"RUHE IN DER KISTE!!")
        self.optical_gates = OpticalGates(callback=callback)
        logger.info("System initialized and ready")
        
def main():
    """Initialize the bird control components"""
    try:
        BirdControl()
        while True:
            time.sleep(5)
            logger.info("System running")

    except KeyboardInterrupt:
        logger.info("Program terminated by user")
    except Exception as e:
        logger.error(f"Unexpected error occurred: {e}")
    finally:
        #motors.cleanup()
        #GPIO.cleanup()
        logger.info("GPIO cleanup completed")

if __name__ == "__main__":
    main()

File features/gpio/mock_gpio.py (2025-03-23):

"""
Mock Library for RPi.GPIO
STABLE - Mock implementation of RPi.GPIO for development and testing
"""
import logging
import os
from typing import Optional, Any, Literal

from .gpio_interface import Channel, PWMProtocol, Value, EventCallback

# Configure logging
logging.basicConfig(level=logging.INFO)
logger = logging.getLogger(__name__)

# Configure logging based on environment
log_level = os.getenv('LOG_LEVEL')
if log_level is not None:
    logger.setLevel(getattr(logging, log_level.upper(), logging.ERROR))
else:
    logger.setLevel(logging.ERROR)

stream_formatter = logging.Formatter('%(asctime)s:%(levelname)s: %(message)s')
stream_handler = logging.StreamHandler()
stream_handler.setFormatter(stream_formatter)
logger.addHandler(stream_handler)

# GPIO Mode constants - must match exactly with RPi.GPIO
BCM: Literal[11] = 11
BOARD: Literal[10] = 10
BOTH: Literal[33] = 33
FALLING: Literal[32] = 32
HARD_PWM: Literal[43] = 43
HIGH: Literal[1] = 1
I2C: Literal[42] = 42
IN: Literal[1] = 1
LOW: Literal[0] = 0
OUT: Literal[0] = 0
PUD_DOWN: Literal[21] = 21
PUD_OFF: Literal[20] = 20
PUD_UP: Literal[22] = 22
RISING: Literal[31] = 31
SERIAL: Literal[40] = 40
SPI: Literal[41] = 41
UNKNOWN: Literal[-1] = -1
VERSION: str = '0.7.0'
RPI_INFO: dict[str, Any] = {
    'MANUFACTURER': 'Sony',
    'P1_REVISION': 3,
    'PROCESSOR': 'BCM2837',
    'RAM': '1G',
    'REVISION': 'a020d3',
    'TYPE': 'Pi 3 Model B+'
}

class _MockPin:
    """Internal class to track pin state"""
    def __init__(self, number: int, mode: int = IN, pull_up_down: int = PUD_OFF, initial: int = LOW):
        self.number = number
        self.mode = mode
        self.pull_up_down = pull_up_down
        self.value = initial
        self.event_callbacks: list[EventCallback] = []
        self.edge_detect: Optional[int] = None
        self.bouncetime = -666



# Global state
_gpio_mode: Optional[Literal[10, 11]] = None
_warnings = True
_rpi3B_pins: list[int] = [2, 3, 4, 7, 8, 9, 10, 11, 14, 15, 17, 18, 22, 23, 24, 25, 27]
_pins: dict[int, _MockPin] = {pin: _MockPin(pin) for pin in _rpi3B_pins}
logger.info(f"MockGPIO initialized with {len(_pins)} pins")

def setmode(mode: Literal[10, 11]) -> None:
    """Set up numbering mode to use for channels."""
    if mode not in [BCM, BOARD]:
        raise ValueError(f"Invalid mode: {mode}")
    _gpio_mode = mode
    logger.info(f"GPIO mode set to: {mode}")

def getmode() -> Optional[Literal[10, 11]]:
    """Get numbering mode used for channels."""
    if _gpio_mode is None:
        return None
    if _gpio_mode is BCM:
        return BCM
    if _gpio_mode is BOARD:
        return BOARD
    else:
        raise ValueError(f"Invalid mode: {_gpio_mode}")

def setup(channel: Channel, direction: int, pull_up_down: int = PUD_OFF, initial: int = -1) -> None:
    """Set up a GPIO channel or list of channels with a direction and (optional) pull/up down control."""
    
    channels = [channel] if isinstance(channel, int) else channel
    for pin in channels:
        _pins[pin] = _MockPin(pin, direction, pull_up_down, initial if initial != -1 else LOW)
        logger.info(f"Setup channel {pin} as {direction} with initial {initial} and pull_up_down {pull_up_down}")

def cleanup(channel: Optional[Channel] = None) -> None:
    """Clean up GPIO channels."""

    if channel is None:
        _pins.clear()
        _gpio_mode = None
        logger.info("Cleaning up all channels")
    else:
        channels = [channel] if isinstance(channel, int) else channel
        for pin in channels:
            _pins.pop(pin, None)
            logger.info(f"Cleaning up channel {pin}")

def input(channel: int) -> bool:
    """Read the value of a GPIO channel."""
    if channel not in _pins:
        raise RuntimeError(f"Channel {channel} not set up")
    logger.info(f"Reading from channel {channel}")
    if _pins[channel].mode == IN:
        return bool(_pins[channel].value)
    else:
        raise RuntimeError(f"Channel {channel} is not set up as an input")

def output(channel: Channel, value: Value) -> None:
    """Output to a GPIO channel or list of channels."""
    channels = [channel] if isinstance(channel, int) else channel
    values = [value] if isinstance(value, (bool, int)) else value
    
    if len(channels) != 1 and len(channels) != len(values):
        raise RuntimeError("Number of channels != number of values")
    
    for i, pin in enumerate(channels):
        if pin not in _pins.keys():
            raise RuntimeError(f"Channel {pin} not set up")
        if _pins[pin].mode != OUT:
            raise RuntimeError(f"Channel {pin} is not set up as an output")
        val = values[0] if len(values) == 1 else values[i]
        _pins[pin].value = 1 if val else 0
        logger.info(f"Output channel {pin} with value {val}")
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

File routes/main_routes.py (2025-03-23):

"""
STABLE
Main route implementations for BirdsOS
Contains all UI route definitions
Last verified: Current
"""
from flask import Blueprint, render_template

main_bp = Blueprint('main', __name__)

@main_bp.route('/')
def dashboard():
    """Main dashboard view"""
    return render_template('dashboard.html')

@main_bp.route('/camera/')
@main_bp.route('/camera')
def camera():
    """Camera management view"""
    return render_template('camera.html')

@main_bp.route('/hardware/')
@main_bp.route('/hardware')
def hardware():
    """Hardware control view"""
    return render_template('hardware.html')

@main_bp.route('/config/')
@main_bp.route('/config')
def config():
    """System configuration view"""
    return render_template('config.html')

@main_bp.route('/maintenance/')
@main_bp.route('/maintenance')
def maintenance():
    """System maintenance view"""
    return render_template('maintenance.html')

@main_bp.route('/analytics/')
@main_bp.route('/analytics')
def analytics():
    """Analytics and statistics view"""
    return render_template('analytics.html') 

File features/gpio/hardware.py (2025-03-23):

"""
GPIO Hardware Constants and Utilities
STABLE - Hardware interface with singleton pattern
"""
import logging
from typing import Optional

from .constants import *
from .gpio_interface import GPIOProtocol, PWMProtocol

logger = logging.getLogger(__name__)

# Makes sure we are not using mock hardware on a real raspberry pi
if not is_raspberrypi():
    try:
        # For mock hardware on non-Raspberry Pi systems
        from . import mock_gpio as GPIO
        from .mock_gpio import PWM as PWM
        logger.info("Using mock GPIO implementation for non-Raspberry Pi system")
        if not isinstance(GPIO, GPIOProtocol):
            raise TypeError("mockgpio does not implement required interface")
        if not isinstance(PWM, PWMProtocol):
            raise TypeError("mockgpio does not implement required interface")
    except:
        raise RuntimeError("Code is not running on a raspberry pi, but Mock import failed")
else:
    # If we are on a raspberry pi, use the real hardware implementation
    try:
        # Try to import the real hardware implementation first
        import RPi.GPIO as GPIO # type: ignore
        from RPi.GPIO import PWM as PWM# type: ignore
        logger.info("Using real Raspberry Pi GPIO hardware")
        if not isinstance(GPIO, GPIOProtocol):
            raise TypeError("RPi.GPIO does not implement required interface")
        if not isinstance(PWM, PWMProtocol):
            raise TypeError("RPi.GPIO does not implement required interface")
    except ImportError:
        raise RuntimeError("Raspberry Pi GPIO library not found")

class PWMInfo:
    """
    Information about a PWM pin.
    """
    pin: int
    frequency: int
    duty_cycle: float | None
    pwm: PWMProtocol

    def __init__(self, pin: int, frequency: int, pwm: PWMProtocol):
        self.pin = pin
        self.frequency = frequency
        self.duty_cycle = None
        self.pwm = pwm
        logger.debug(f"Created PWM instance for pin {pin} at {frequency}Hz")
        
class GPIOHardware:
    """
    Manages GPIO operations with support for real Raspberry Pi hardware.
    Implements singleton pattern to ensure single point of GPIO control.
    """
    # Singleton instance
    _instance = None
    _initialized = False

    def __new__(cls):
        if cls._instance is None:
            cls._instance = super(GPIOHardware, cls).__new__(cls)
        return cls._instance

    def __init__(self):
        # Only run initialization once
        if self._initialized:
            return
            
        self._initialized = True
        self.gpio = GPIO
        self.gpio.setmode(BCM)
        logger.info("GPIO Manager initialized in BCM mode")            
        self._valid_pins: list[int] | None = None
        self.RPI_INFO = GPIO.RPI_INFO
        logger.debug("GPIO Hardware instance initialized")

    def get_valid_pins(self) -> list[int]:   
        """Get valid GPIO pins by checking gpio_function for all possible pins."""
        if hasattr(self, "_valid_pins"):
            if self._valid_pins is not None:
                return self._valid_pins        
       
        valid_pins: list[int] = []
        # Check all possible BCM pins (0-27 should cover all Pi models)
        for pin in range(100):
            try:
                mode = self.gpio.gpio_function(pin)
                # If we can get the function, it's a valid GPIO pin
                # Only include pins that can be used for input/output
                if mode in [IN, OUT]:
                    valid_pins.append(pin)
            except (ValueError, RuntimeError):
                # Pin doesn't exist or is not a valid GPIO
                continue
        
        if not valid_pins:
            raise RuntimeError("No valid pins found")
        
        self._valid_pins = sorted(valid_pins)
        logger.debug(f"Valid pins found: {self._valid_pins}")
        return self._valid_pins

    def setup_input_pin(self,
                       pin: int, 
                       pull_up_down:PullUpDown=PUD_OFF, 
                       edge_detection:bool=False,
                       bouncetime:int=200,
                       callback:EventCallback|None=None
                       ) -> None:
        """
        Set up a pin as input with optional edge detection.
        Pull-up/down is optional but recommended for stable readings.

        Args:
            pin: The GPIO pin number (BCM numbering)
            pull_up_down: Pull up/down resistor setting (PUD_OFF, PUD_UP, or PUD_DOWN)
            edge_detection: Whether to enable edge detection
            bouncetime: Bounce time in ms for edge detection
            callback: Required if edge_detection is True, must not be provided if edge_detection is False.
                     Will be called with (pin, state) where state is the current pin state.
        """
        if pull_up_down not in [PUD_OFF, PUD_UP, PUD_DOWN]:
            raise ValueError("Invalid pull-up/down value")
        
        self.gpio.setup(pin, IN, pull_up_down=pull_up_down)
        pud_name = {PUD_OFF: "OFF", PUD_UP: "UP", PUD_DOWN: "DOWN"}[pull_up_down]
        logger.info(f"Setup pin {pin} as input with pull-up/pull-down value '{pud_name}'")

        if (edge_detection and not callback) or (not edge_detection and callback):
            raise ValueError("Callback must be provided with edge_detection=True and must not be provided with edge_detection=False")
        
        if edge_detection:
            try:
                # Create a wrapper that adapts our callback to RPi.GPIO's expected signature
                def gpio_callback(pin: int) -> None:
                    state = self.get_pin_state(pin)
                    if callback is not None:
                        callback(pin, state)

                self.gpio.add_event_detect(pin, BOTH, callback=gpio_callback, bouncetime=bouncetime)
                logger.debug(f"Set up edge detection on pin {pin} with state-aware callback")
            except RuntimeError as e:
                logger.error(f"Failed to set up edge detection on pin {pin}: {e}")
                raise RuntimeError(f"Edge detection setup failed for pin {pin}. "
                                 f"Ensure valid pin number and proper permissions.")

    def setup_output_pin(self, pin: int, initial_state: PinState = UNDEFINED) -> None:
        """
        Set up a pin as output with optional initial state.
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

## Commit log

2024-10-25 Second initial commit adding all design files
    [BirdBox_first_funnel_2020.stl, BirdBox_lid_bracket.stl, BirdBox_lid_servo_lift_mechanism.stl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]
2024-11-17 Added parts for construction
    [BottomVibroMountPlate.FCStd, VibroMotorMount-Body.stl, VibroMotorMount-V2.stl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]
2024-11-17 Added measurments and part for construction
    [Funnel2OpticalGate.FCStd, FunnelOpticalGateReciever.FCStd]
2025-01-17 Modified Camera Case
    [Bottom.FCStd, Bottom_Mount.FCStd, Bottom_MountHorizontal.FCStd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]
2025-01-17 Added Camera Case Source
2025-01-17 add raspberry project and Readmy
2025-01-19 feat: implement core BirdsOS functionality
    - Add camera system with mock implementation and streaming\n- Implement GPIO abstraction layer with Pi detection\n- Create web interface with simulators\n- Set up RESTful API endpoints for system con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
2025-01-20 NutReciever und CameraCase verbessert
    [Bottom_CameraCase.stl, Bottom_MountHorizontal.FCStd, Buttom_CameraCase.stl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]
2025-01-21 fix(tests): resolve camera test import paths and verify functionality
    - Add parent directory to Python path in test files - Fix import statements for camera and storage manager modules - Verify all camera tests pass successfully including motion detection - Update test documentation and assertions
2025-01-21 camera läuft
2025-01-22 clean slate
    [BirdBox_first_funnel_2020.stl, BirdBox_lid_bracket.stl, BirdBox_lid_servo_lift_mechanism.stl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]
2025-01-23 fix(gpio): update tests and routes - Fix test expectations, route paths, and template structure
    [routes.py, test_error_handling.py, test_ui.py]
2025-01-23 test: fix camera manager unit tests - Fix blocking behavior by mocking threading.Lock - Fix mock setup in test_initialize_failure - Add proper cleanup verification - Update resolution testing - Add p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
2025-01-29 changed gpio to use callbacks. Added tests. fixed version check and update and added tests
    [manager.py, routes.py, system_routes.py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]
2025-01-30 fixed bug in initializing gpio (install it) and wrong raspberry detection in tests
    [hardware.py]
2025-01-30 fixed gpio init bug
    [manager.py, system_routes.py, test_error_handling.py]
2025-01-30 In the GPIO manager: Removed automatic pin configuration during initialization Added proper pin configuration state tracking with None for unconfigured pins Updated pin state checking to properly han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
    [manager.py]
2025-01-30 Simplified the GPIO manager to be the single source of truth: Removed the separate mock state tracking Unified pin state tracking for both real and mock modes Made pin configuration explicit and cons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
    [manager.py]
2025-01-30 Added back essential methods that tests depend on: get_available_pins(): Returns list of valid GPIO pins get_configured_pins(): Returns dictionary of configured pins and their modes Simplified test c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
    [manager.py]
2025-01-30 The key changes are: In the GPIO manager: More robust initialization checking Only clean up if mode isn't already set Better handling of mode conflicts Selective cleanup of only configured pins Prope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
    [manager.py]
2025-01-30 Made initialization more resilient: If already initialized in BCM mode, don't reinitialize Try to reinitialize in configure_pin if not initialized Handle cleanup errors gracefully Improved cleanup be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
    [manager.py]
2025-01-30 The key changes are: Added proper dependency injection: Made app fixture depend on gpio_manager Added gpio_manager dependency to all test functions Imported gpio_manager from routes Added initializat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
    [test_routes.py]
2025-01-30 The key changes made are: Fixed API response handling: Check for data.pins instead of data.status Better error handling with data.error Use response.ok to check HTTP status Improved UI feedback: Adde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
2025-02-07 Improve GPIO pin state and configuration handling
    - Enhanced pin state retrieval in routes to handle unconfigured pins
    - Added state and mode validation before pin state changes
    - Updated GPIO controller to check pin configuration before toggling
    - Improved error handling and logging for pin state operations
    - Added more informative UI feedback for pin actions
    [routes.py]
2025-02-09 fixed wrong typing of hardware constants
    [manager.py, routes.py, test_routes.py]
2025-02-17 Refactor GPIO Package with Mock Hardware and Constants
    - Added mock GPIO implementation for non-Raspberry Pi development
    - Created constants module to centralize GPIO-related type hints and values
    - Introduced GPIO interface protocol for consistent hardware implementations
    - Updated hardware module to dynamically select GPIO implementation
    - Improved platform detection and hardware initialization logic
    - Enhanced test coverage for GPIO hardware functionality
2025-02-17 Update logging configuration for cross-platform log directory support
    - Use platform-specific log directory based on IS_RASPBERRYPI constant
    - Fallback to user's home directory logs for non-Raspberry Pi environments
    - Ensure log directory creation works consistently across platforms
2025-02-17 Refactor GPIO WebSocket and State Management
    - Update GPIO routes to improve WebSocket communication
    - Modify initial state retrieval and periodic updates
    - Add type hints and error handling improvements
    - Simplify GPIO state tracking and reporting mechanism
    [app.py, routes.py]
2025-02-17 Enhance GPIO WebSocket Client with Improved Logging and State Management
    - Add console logging for WebSocket events and pin updates
    - Implement dropdown population flag to prevent redundant updates
    - Improve pin mode display (converting numeric mode to 'Input'/'Output')
    - Add more detailed console logging for pin configuration and state changes
2025-02-17 Add Postman API Collection for BirdBox System
    - Create comprehensive Postman collection for BirdBox API
    - Include endpoints for System, Camera, GPIO, and Storage management
    - Define request methods, URLs, and descriptions for each API endpoint
    - Set up base URL variable for local development
2025-02-20 Implement Bird Control System with Motor and Optical Gate Components
    - Add motor control module with PWM frequency and duty cycle management
    - Implement optical gates for detecting bird movement
    - Create configuration settings for GPIO pins and motor parameters
    - Update app initialization to include bird control system setup
    - Enhance GPIO manager with PWM pin configuration and management
    - Refactor logging and hardware initialization in main application
2025-02-20 Update GPIO and Logging Imports
    - Replace custom logging import with standard Python logging
    - Switch from python3-rpi.gpio to python3-rpi-lgpio in setup script
    - Remove redundant GPIO package removal steps
    - Standardize logging import across motor_controller and optical_gates modules
    [motor_controller.py, optical_gates.py]
2025-02-20 Refactor Bird Control System and Add Logging Configuration
    - Create centralized logging configuration in `config/logging.py`
    - Update `birdcontrol.py` with simplified control flow and callback mechanism
    - Modify `optical_gates.py` to enable callback functionality
    - Adjust GPIO manager to improve pin configuration logging
    - Reduce motor initial frequency in `settings.py`
2025-02-20 Refactor GPIO Management with Enhanced Callback and Pin Configuration
    - Implement flexible pin callback system with support for multiple callbacks
    - Add `watch_pin()` method to monitor pin states without reconfiguration
    - Introduce `clear_pin()` method for resetting pin configurations
    - Enhance error handling and logging for GPIO pin management
    - Support optional `on_clear` callback for pin-related cleanup
    - Improve pin state tracking and callback triggering mechanisms
    [hardware.py, manager.py, routes.py]
2025-02-20 Simplify BirdControl Initialization and Remove Optical Gates Setup
    - Replace MotorController with BirdControl in app initialization
    - Remove explicit motor PWM turning on step
    - Delete optical gates initialization code
    - Streamline bird control system startup process
    [app.py]
2025-02-20 Enhance BirdControl with Standalone Mode and Configuration Updates
    - Add `run_birdcontrol.py` for standalone BirdControl execution
    - Modify `birdcontrol.py` to include running state and timeout management
    - Update `motor_controller.py` to comment out second motor pin
    - Add `MAX_ON_TIME` configuration in `settings.py`
    - Update logging configuration to always use DEBUG level
    - Add systemd service for standalone BirdControl in `setup.sh`
2025-02-20 Update BirdControl Configuration Import and Timeout Setting
    - Import MOTOR_CONFIG from settings alongside PIN_CONFIG
    - Replace PIN_CONFIG timeout with MOTOR_CONFIG timeout
    - Simplify configuration management for bird control system
    [birdcontrol.py]
2025-03-23 Added several parts
    [BirdBox_vibr_flywheel_3mm.stl, BottomVibroMountPlate.FCStd, Vibrating_Motor_Mount-Linear_Vibrator_Measured.FCStd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]
2025-05-09 feat:Added Bill of Materials
